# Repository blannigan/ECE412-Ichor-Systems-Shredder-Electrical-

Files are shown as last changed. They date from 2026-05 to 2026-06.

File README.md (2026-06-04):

# Universal Plastic Shredder V2.0 — Electrical System

**ECE 412 Senior Project Development I/II · Portland State University · Winter–Spring 2026**

Repository owner: **MME / Ichor Systems** ([@blannigan](https://github.com/blannigan)) — transferred from the EE team at the end of term for long-term stewardship.

Industry Sponsor: **MME / Ichor Systems** (Bridget Lannigan)  
Faculty Advisors: Prof. Andrew Greenberg, Dr. Jonathan Bird (EE), Robert Paxton (ME)

**Team "I'm so Shredded inc." — original authors, retained as collaborators with write access:**

| Name | Email |
|---|---|
| Bao Nguyen | baon@pdx.edu |
| Fearghus Tyler | fearghus@pdx.edu |
| Yaqoub Rabiah | yrabiah@pdx.edu |
| Fox Kang | foxkang@pdx.edu |

---

## Project Overview

Ichor Systems generates significant plastic waste (PVC, polypropylene, LDPE) during semiconductor equipment manufacturing. Existing commercial shredders are either too expensive or underpowered for their thick-material needs (0.25–0.5" rigid sheets). This project designs and builds the **electrical control and power system** for a new industrial-grade plastic shredder — Universal Plastic Shredder V2.0.

The mechanical structure and cutting blades are handled by a separate ME team. The EE team is responsible for:

- VFD-based motor control (3–5 HP, target 70–90 RPM output shaft speed)
- HMI operator interface (AutomationDirect EA1-T4CL C-more Micro-Graphic touch panel, serial to the PLC)
- Safety systems: two-hand start, emergency stop, lid interlock, overload/overcurrent protection
- PLC ladder logic for control sequencing (DirectLogic 205 / Direct Automation)
- Status indicator lights (Power, Running, Fault)
- Electrical protection: fuses, breakers, motor contactor, thermal shutdown

Design follows **NFPA 70 (NEC)** guidance and **NEMA enclosure** practices. Total project budget is $3,000 (EE portion ~$1,000).

---

## Requirements Summary

**Must:**
- Shred plastic into ~1-inch pieces when integrated with ME system
- Use a controllable VFD; support 3–5 HP motor at 70–90 RPM
- Follow NFPA-70 (NEC) electrical design guidance
- Include emergency stop, overcurrent/overload protection, and at least one safety interlock
- Include an HMI for operator control and status display
- Stay within the **$1,000 EE-team budget** (the overall $3,000 project budget is split across ME and EE; EE owns $1,000)

**Should:**
- Include clear status and fault indicator lights
- Follow NEMA enclosure guidelines
- Have clearly labeled controls

**May (if time/budget allow):**
- Wireless monitoring (read-only)
- Data logging
- Additional safety sensing (capacitive touch, thermal)

---

## Repository Structure

```
docs/           Numbered project documents (term1_week04_Project_Proposal → term2_week10_Final_Report)
BOM/            Bill of materials and component selection spreadsheets
CAD/            Mechanical CAD zip archive and Inventor part files (Part1–Part10)
electrical/     Circuit logic diagrams and deadman circuit documentation
PLC/            Shredder ladder logic program and point list (.xlsx / .pdf)
HMI/            HMI project file (MagicPanel .mgp)
```

---

## Final Report

The EE final report lives in `docs/term2_week10_Final_Report/`:

- **`docs/term2_week10_Final_Report/Final_Report.pdf`** — the built report (PSU MCECS style).
- **`docs/term2_week10_Final_Report/src/Final_Report.tex`** — LaTeX source.
- **[`docs/term2_week10_Final_Report/Report_Setup.md`](docs/term2_week10_Final_Report/Report_Setup.md)** — **how to build, edit, and
  regenerate the report** (toolchain, packages, compile steps, and how to
  rebuild the point-list appendix from `PLC/Point_List.xlsx`). Start here if you
  want to work on the report.
- `docs/term2_week10_Final_Report/src/appendix_pointlist.tex` / `docs/term2_week10_Final_Report/src/gen_pointlist.py` — the auto-generated
  point-list appendix and its generator.

---

## System Architecture

**Hardware subsystems:**
- AC power input → main disconnect (PowerTec 71008) → branch fuses / breakers
- 24 VDC supply (Mean Well NDR-480-24) for control wiring
- Mitsubishi SD-N35 motor contactor (E-stop hardwired in series with the coil)
- VFD (Huanyang HY02D211B-T), motor speed and direction driven by a 0–10 V analog command from the PLC and a hardwired RUN_FWD / RUN_REV / RESET trio
- 3–5 HP motor + gearbox (ME interface)
- AutomationDirect EA1-T4CL C-more Micro-Graphic HMI (operator interface)
- Safety circuit: two-hand start (deadman) buttons, E-stop, motor contactor, capacitive-touch safety input (wired to PLC X7)

**PLC (DirectLOGIC 205 rack with H2-DM1E CPU):**
The PLC is the system controller. All run-permit logic, jam recovery, the
3-strike lockout, and the HMI screen-change behavior live in the ladder
program (see Section 6 of the Final Report and `PLC/Point_List.pdf` for the
full I/O map). Modules in the rack:

| Slot | Module | Role |
|---|---|---|
| 0 | H2-DM1E | CPU + Ethernet |
| 1 | D2-08ND3 | 8-point DC discrete input (pushbuttons, E-stop monitor, VFD fault, cap touch) |
| 2 | F2-08AD-1 | 8-channel analog current input (VFD motor current monitor) |
| 3 | F2-04RTD | 4-channel RTD input (motor temperature, future) |
| 4 | D2-08TR | 8-point relay output (VFD RUN_FWD / RUN_REV / RESET, panel LEDs) |
| 5 | F2-08DA-2 | 8-channel analog voltage output (0–10 V speed reference to VFD VI) |

Program file: `PLC/src/Shredder_Ladder_Logic_v1.dmd`
Industrial standard: the entire control program and the operator interface
are built on AutomationDirect DirectLOGIC / Do-more / C-more hardware
rather than a hobby-grade microcontroller stack. ESP32 / Arduino were
considered for the HMI early on and rejected: the sponsor build needs an
industrial-rated touch panel and a PLC-based control program for
maintainability, safety review, and alignment with NFPA 79 / NEMA practice.

**HMI (EA1-T4CL C-more Micro-Graphic, `HMI/HMI_413.mgp`):**
Four screens, 27 PLC tags. The HMI is a display + button panel only; all
logic runs in the PLC ladder program. Screens:

  1. MOTOR CONTROL  — forward / reverse / stop, speed adjust (V2000)
  2. MOTOR TELEMETRY — frequency, current, voltage, RPM read-back
  3. ERROR (red backlight) — jam, capacitive trip, and E-stop indicators
  4. TEST — engineering / commissioning screen (soft deadman, soft jam)

**Operator workflow:**
1. Power on → safety check
2. Press two-hand start buttons simultaneously to run motor
3. Hand-feed plastic sheets into shredder
4. Normal stop via Stop button, or E-stop if needed
5. Collect shredded output (~1-inch pieces)

---

## Prior Work

A 2023–2024 PSU capstone team built a working 2 HP plastic shredder for the EPL that shredded household plastics with basic VFD, two-hand start, and E-stop. This project scales to industrial-grade plastics and adds motor current monitoring, automatic jam-clearing (auto forward/reverse), thermal shutdown, improved safety interlocks, a proper contactor, and a full HMI.

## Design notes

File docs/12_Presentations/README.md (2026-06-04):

# Presentations

PowerPoint decks the team built for advisor / sponsor reviews and
the final demo. Imported from Google Drive at end of term.

| # | Deck | When |
|---|---|---|
| 01 | `01_Slides_Deck_1.pptx` | First Universal Plastic Shredder V2.0 review deck (early Spring) |
| 02 | `02_Slides_Deck_2.pptx` | Second review deck (mid Spring) |
| 03 | `03_Ted_Talk_2.pptx` | Class "TED talk" presentation #2 |
| 04 | `04_Final_Demo_5min.pptx` | End-of-term 5-minute demo for the capstone showcase |

The decks were authored in PowerPoint via Drive; open in PowerPoint
or LibreOffice Impress.

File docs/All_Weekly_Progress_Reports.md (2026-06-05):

# Universal Plastic Shredder V2.0 — Weekly Progress Reports

**Course:** ECE 412/413 (Spring 2026)  
**Sponsor:** MME / Ichor Systems  
**Team:** Bao Nguyen, Fearghus Tyler, Yaqoub Rabiah, Fox Kang

---

## 🔑 Key hardware referenced

| System | Part | Role / interface |
|---|---|---|
| **VFD** | Huanyang **HY02D211B-T** | Motor drive. Speed ref on **VI** (0–10 V, `PD002=1`), current monitor on **VO** (`PD054=1`), fault relay **FA/FC** (`PD052=02`), run inputs **FOR/REV/RST** (sinking to DCM). |
| **Motor** | GE **5KE182BC205B** (bench, Winter / most of Spring) → IronHorse **MTCP2-002** (production, swapped in during Week 10) | 3-phase. Bench motor: 3 HP, 230 V, FLA ≈ 7.6 A, 1750 RPM. Production motor: 2 HP, 230 V, **5.93 A**, 1735 RPM, NEMA 145TC TEFC IP55, VFD-rated 1.0 SF. Phases **U/V/W → T1/T2/T3** via 4 mm banana sockets. |
| **PLC** | DirectLOGIC 205, **H2-DM1E** CPU | DI **X0–X7** (`D2-08ND3`), relay out **Y0–Y7** (`D2-08TR`), current-in **F2-08AD-1**, 0–10 V out **F2-08DA-2**. |
| **HMI** | C-More **EA1-T4CL** | 4" touch panel, serial link to CPU. |
| **Contactor** | Mitsubishi **SD-N35** | In the hardwired E-stop chain (coil **A1/A2**); switches the VFD feed. |
| **E-stop** | Eaton **E22B1** (NC) | Drops the contactor coil; state monitored on PLC **X4**. |
| **Braking resistor** | ATO **APCS-300R30-AD** | 300 W / 30 Ω on VFD **P+/PR**. |

## 🗂️ Report index

**Winter term**

| Date | Focus |
|---|---|
| 2025-12-17 | Kickoff coordination meeting; component research begins |
| 2026-01-03 | Compare motors / HMIs / safety sensors |
| 2026-01-09 | Sponsor + advisor goal/budget review |
| 2026-01-16 | Motor-control & safety strategy; first motor+VFD bench test |
| 2026-01-23 | Electrical design starts; BOM for initial purchases; AutoCAD setup |
| 2026-02-02 | Prototype build; safety-sensor circuit |
| 2026-02-06 | Schematic + ME coordination |
| 2026-02-13 | Advisor coordination meeting |
| 2026-02-27 | Documentation & presentation prep; BOM revision |
| 2026-03-06 | Parts arrived — fit & wire the prototype |
| 2026-03-13 | VFD/motor bring-up; HMI GUI |
| 2026-03-16 | Finalize documentation before spring break |

**Spring term**

| Wk | Date | Focus |
|---|---|---|
| 1 | 2026-04-03 | Post-break reset; points list; E-stop → contactor |
| 2 | 2026-04-10 | PLC ↔ circuit integration; cap-touch (small scale) |
| 3 | 2026-04-17 | Relay-module fix; analog modules; HMI scaling |
| 4 | 2026-04-24 | Current → voltage (0–10 V) control swap; VFD reprogram |
| 5 | 2026-05-01 | Presentation; cap-touch prototype; braking resistor sizing |
| 6 | 2026-05-08 | Midterm week (light); documentation |
| 7 | 2026-05-15 | Enclosure panel build; overcurrent-signal logic |
| 8 | 2026-05-22 | Panel wiring; ME parts hand-off |
| 9 | 2026-05-30 | Documentation push (report, manual, schematics) |
| 10 | 2026-06-06 | Final report & capstone demo |

---

# Winter Term (Dec 2025 – Mar 2026)

## Report date: 2025-12-17

### ✅ Last week  ·  _hours in parentheses_

**Team Review**
- The electrical and mechanical teams held the first coordination meeting for the shredder project.
- We discussed the overall system design, safety systems, and motor-control ideas.
- The team also set up communication tools and began researching components.

**Bao Nguyen**
- Created Discord server for team communication. (1)
- Attended coordination meeting with ME team. (1)
- Began researching HMI display options. (3)

**Fearghus Tyler**
- Discussed motor requirements with mechanical team. (2)
- Attended coordination meeting with ME team. (1)
- Researched possible motor options. (2)

**Yaqoub Rabiah**
- Started researching VFD motor-control systems. (3)
- Attended coordination meeting with ME team. (1)

**Fox Kang**
- Started researching safety sensors and safety concepts. (3)
- Attended coordination meeting with ME team. (1)

### 🎯 Next week

**Team Plan**
- Continue researching components and begin building comparison tables for motors, sensors, and control systems.

**Bao Nguyen**
- Research HMI options and telemetry display ideas. (3)

**Fearghus Tyler**
- Begin creating preliminary electrical BOM. (3)

**Yaqoub Rabiah**
- Research VFD telemetry and monitoring features. (3)

**Fox Kang**
- Continue researching safety detection methods. (3)

### 🚧 Blocked

**Bao Nguyen**
- Waiting for motor requirements from mechanical team.

**Fearghus Tyler**
- Waiting for gearbox specifications.

**Yaqoub Rabiah**
- Waiting for VFD model.

**Fox Kang**
- None.

---

## Report date: 2026-01-03

### ✅ Last week  ·  _hours in parentheses_

**Team Review**
- The team continued researching electrical components for the shredder system.
- Motors, HMIs, and safety sensors were compared.
- Early ideas for the electrical control system were discussed.

**Bao Nguyen**
- Researched HMI display options. (3)
- Reviewed possible telemetry information to display. (2)

**Fearghus Tyler**
- Began building the electrical BOM for the initial test setup — motor, VFD, contactor, PLC rack + modules, HMI, breaker, power switch, and 12/10 AWG wire. (3)

**Yaqoub Rabiah**
- Compared VFD options and specifications. (3)

**Fox Kang**
- Continued safety-sensor research. (3)

### 🎯 Next week

**Team Plan**
- Narrow down hardware options and begin planning electrical architecture.

**Bao Nguyen**
- Work on system block diagram. (3)

**Fearghus Tyler**
- Expand electrical BOM. (3)

**Yaqoub Rabiah**
- Research PLC integration with VFD. (3)

**Fox Kang**
- Continue researching safety interlocks. (3)

### 🚧 Blocked

**Bao Nguyen**
- Waiting for enclosure dimensions.

**Fearghus Tyler**
- Waiting for torque specifications.

**Yaqoub Rabiah**
- Waiting for PLC to arrive.

**Fox Kang**
- Stuck on figuring out the type of technology for the safety sensor.

---

## Report date: 2026-01-09

### ✅ Last week  ·  _hours in parentheses_

**Team Review**
- The team met with the faculty advisor and industry sponsor to review project goals.
- Budget, motor power, and safety requirements were discussed.

**Bao Nguyen**
- Attended sponsor meeting. (1)
- Researched HMI communication options. (3)

**Fearghus Tyler**
- Continued the electrical BOM — added the Huanyang HY02D211B-T VFD, contactor, push buttons, PLC rack + modules, C-More EA1-T4CL HMI, circuit breaker, power switch, and 12/10 AWG wire. (3)
- Attended sponsor meeting. (1)

**Yaqoub Rabiah**
- Researched VFD control and monitoring options. (4)

**Fox Kang**
- Continued researching safety sensors. (3)

### 🎯 Next week

**Team Plan**
- Start developing electrical system architecture.

**Bao Nguyen**
- Work on system layout diagram. (3)

**Fearghus Tyler**
- Continue updating BOM. (3)

**Yaqoub Rabiah**
- Compare VFD options. (3)

**Fox Kang**
- Research safety-sensor placement. (3)

### 🚧 Blocked

**Bao Nguyen**
- Waiting for motor specs.

**Fearghus Tyler**
- Waiting for gearbox decision.

**Yaqoub Rabiah**
- Waiting on PLC.

**Fox Kang**
- Waiting on HMI.

---

## Report date: 2026-01-16

### ✅ Last week  ·  _hours in parentheses_

**Team Review**
- The electrical team reviewed motor-control strategies and safety systems.
- Design ideas for the electrical system were discussed.

**Bao Nguyen**
- Tested small motor and VFD setup. (4)

**Fearghus Tyler**
- Worked with mechanical team on gearbox ideas. (3)

**Yaqoub Rabiah**
- Reviewed VFD specifications. (3)

**Fox Kang**
- Created accident-scenario safety flow chart. (3)

### 🎯 Next week

**Team Plan**
- Continue developing electrical control-system design.

**Bao Nguyen**
- Work on electrical control-circuit layout. (3)

**Fearghus Tyler**
- Update electrical BOM. (3)

**Yaqoub Rabiah**
- Continue VFD research. (3)

**Fox Kang**
- Continue safety-system research. (3)

### 🚧 Blocked

**Bao Nguyen**
- Waiting for gearbox decision.

**Fearghus Tyler**
- Waiting for enclosure size.

**Yaqoub Rabiah**
- Waiting on equipment to program PLC.

**Fox Kang**
- Choosing the correct parts for the safety sensors.

---

## Report date: 2026-01-23

### ✅ Last week  ·  _hours in parentheses_

**Team Review**
- The team began developing the electrical design and continued coordination with the mechanical team.

**Bao Nguyen**
- Worked on electrical system design. (3)

**Fearghus Tyler**
- Updated the electrical BOM for the first round of purchases (VFD, contactor, PLC rack/modules, HMI). (3)
- Set up the AutoCAD schematic drawings per these specs — learning the workflow: creating reusable component blocks, transferring blocks between drawings, and setting up the sheet / title-block templates.

**Yaqoub Rabiah**
- Began PLC control-logic planning. (3)

**Fox Kang**
- Continued safety-system research. (3)

### 🎯 Next week

**Team Plan**
- Start building prototype circuits and system diagrams.

**Bao Nguyen**
- Design electrical circuit diagram. (3)

**Fearghus Tyler**
- Continue component sourcing. (3)

**Yaqoub Rabiah**
- Develop PLC logic structure. (3)

**Fox Kang**
- Develop safety-system concept. (3)

### 🚧 Blocked

**Bao Nguyen**
- Waiting for motor specs.

**Fearghus Tyler**
- None.

**Yaqoub Rabiah**
- None.

**Fox Kang**
- None.

---

## Report date: 2026-02-02

### ✅ Last week  ·  _hours in parentheses_

**Team Review**
- The team worked on prototype development and safety-system concepts.

**Bao Nguyen**
- Began building electrical test rig. (4)

**Fearghus Tyler**
- Worked on the electrical schematic in AutoCAD — built out component blocks and the power-distribution sheet. (3)

**Yaqoub Rabiah**
- Developed PLC control logic. (3)

**Fox Kang**
- Requested capacitive-sensor samples. (2)

### 🎯 Next week

**Team Plan**
- Continue prototype testing and system development.

**Bao Nguyen**
- Continue test-rig development. (3)

**Fearghus Tyler**
- Improve schematic design. (3)

**Yaqoub Rabiah**
- Continue PLC programming. (3)

**Fox Kang**
- Develop safety-sensor circuit. (3)

### 🚧 Blocked

**Bao Nguyen**
- Waiting for some parts to arrive.

**Fearghus Tyler**
- None.

**Yaqoub Rabiah**
- None.

**Fox Kang**
- Waiting for sensor samples.

---

## Report date: 2026-02-06

### ✅ Last week  ·  _hours in parentheses_

**Team Review**
- Continued electrical design work and coordination with the mechanical team.

**Bao Nguyen**
- Worked on wiring prototype components. (3)

**Fearghus Tyler**
- Updated the AutoCAD schematic diagrams (block edits and layer cleanup). (3)

**Yaqoub Rabiah**
- Continued PLC logic work. (3)

**Fox Kang**
- Worked on safety-system design. (3)

### 🎯 Next week

**Team Plan**
- Continue system testing and design improvements.

**Bao Nguyen**
- Continue prototype wiring. (3)

**Fearghus Tyler**
- Review schematic design. (3)

**Yaqoub Rabiah**
- Continue PLC programming. (3)

**Fox Kang**
- Continue safety-system research. (3)

### 🚧 Blocked
- None.

---

## Report date: 2026-02-13

### ✅ Last week  ·  _hours in parentheses_

**Team Review**
- The team met with the advisor to discuss project coordination and integration with the mechanical design.

**Bao Nguyen**
- Attended advisor meeting. (1)
- Worked on electrical layout planning. (2)

**Fearghus Tyler**
- Continued the AutoCAD schematic design — refining component blocks and wiring out the control sheet. (3)
- Attended advisor meeting. (1)

**Yaqoub Rabiah**
- Worked on PLC logic improvements. (3)
- Attended advisor meeting. (1)

**Fox Kang**
- Updated safety documentation. (3)
- Attended advisor meeting. (1)

### 🎯 Next week

**Team Plan**
- Continue electrical design and documentation work.

**Bao Nguyen**
- Continue planning the panel/electrical layout — place the VFD, contactor, 24 V PSU, and branch breakers, and rough out control-wire routing for the cabinet.

**Fearghus Tyler**
- Continue the wiring schematics; finalize the power-distribution and control sheets once the updated enclosure CAD arrives from the ME team.

**Yaqoub Rabiah**
- Continue refining the PLC ladder logic — deadman permissive, start/stop, and I/O mapping against the points list.

**Fox Kang**
- Continue the safety-system documentation and evaluate capacitive-sensor options for the operator-presence interlock.

### 🚧 Blocked

**Bao Nguyen**
- Panel/electrical layout depends on the ME enclosure dimensions, still pending.

**Fearghus Tyler**
- Waiting for updated CAD from ME team.

**Yaqoub Rabiah**
- PLC I/O scaling depends on the final analog-module / VFD decision, still pending.

**Fox Kang**
- Still selecting the capacitive-sensor technology before ordering parts.

---

## Report date: 2026-02-27

### ✅ Last week  ·  _hours in parentheses_

**Team Review**
- The team focused on preparing documentation and presentation materials.

**Bao Nguyen**
- Updated electrical design diagrams. (3)

**Fearghus Tyler**
- Reviewed component selections and revised the BOM — switched the production-motor candidate to a PE145TC-2-4 (2 HP, 145TC, 1800 RPM, 3-phase TEFC) and added the NBE7 circuit breaker. (3)

**Yaqoub Rabiah**
- Reviewed PLC logic. (3)

**Fox Kang**
- Updated safety documentation. (3)

### 🎯 Next week

**Team Plan**
- Continue preparing final presentation materials.

**Bao Nguyen**
- Finalize the electrical design diagrams (system block diagram and control-circuit layout) for the presentation.

**Fearghus Tyler**
- Finalize the component-selection list / BOM (VFD, PLC, HMI, contactor, breakers, PSU) for the presentation.

**Yaqoub Rabiah**
- Finalize the PLC control-logic write-up and clean up the ladder comments for the presentation.

**Fox Kang**
- Finalize the safety documentation — E-stop chain, interlocks, and the accident-scenario flow chart — for the presentation.

### 🚧 Blocked
- None.

---

## Report date: 2026-03-06

### ✅ Last week  ·  _hours in parentheses_

**Team Review**
- The team finally got the parts they requested.

**Bao Nguyen**
- Fit parts to our prototype and wire it. (3)

**Fearghus Tyler**
- Fit parts to our prototype and wire it. (3)

**Yaqoub Rabiah**
- Started figuring out C-more to program the HMI. (3)

**Fox Kang**
- Cargo delay; exploring backup plans. (2)

### 🎯 Next week

**Team Plan**
- Try figuring out the VFD phases to have a working motor.

**Bao Nguyen**
- Continue wiring the prototype and bring up the VFD + motor combo — verify phase wiring and get the motor spinning under VFD control.

**Fearghus Tyler**
- Continue fitting and landing the newly arrived parts on the protoboard and tidy up the control wiring.

**Yaqoub Rabiah**
- Continue learning C-more and building out the HMI screens (Ready/Running/Fault, start/stop, status display).

**Fox Kang**
- Pursue a capacitive-touch backup approach while waiting on the chip — breadboard a simple touch sensor and sketch the X7 stop interface.

### 🚧 Blocked

**Bao Nguyen**
- Waiting on E-stop switch.

**Fearghus Tyler**
- Schematic finalization waiting on the ME team's enclosure dimensions.

**Yaqoub Rabiah**
- Still getting C-more set up to program the HMI.

**Fox Kang**
- Cargo delay on capacitive-touch parts.

---

## Report date: 2026-03-13

### ✅ Last week  ·  _hours in parentheses_

**Team Review**
- Started wiring up our prototype and getting the VFD to work.

**Bao Nguyen**
- Work on the VFD and motor combo. (3)

**Fearghus Tyler**
- Work on the VFD and motor combo. (3)

**Yaqoub Rabiah**
- Continued developing the HMI GUI. (3)

**Fox Kang**
- Get the capacitive-touch chip and prepare for the demo. (3)

### 🎯 Next week

**Team Plan**
- Finalize the documentation before spring break.

**Bao Nguyen**
- Continue VFD/motor bring-up — tune the basic run parameters — and document the wiring/parameter setup before spring break.

**Fearghus Tyler**
- Continue the VFD/motor wiring and update the schematics to match the as-built prototype.

**Yaqoub Rabiah**
- Continue developing the HMI GUI — refine the screen layout and link the tags to the PLC.

**Fox Kang**
- Prepare the capacitive-touch chip for the demo — wire it up and verify a basic touch trip.

### 🚧 Blocked
- None.

---

## Report date: 2026-03-16

### ✅ Last week  ·  _hours in parentheses_

**Team Review**
- The team finalized project documentation and presentation materials.

**Bao Nguyen**
- Updated diagrams and documentation. (3)

**Fearghus Tyler**
- Reviewed schematic documentation. (2)

**Yaqoub Rabiah**
- Reviewed PLC control-logic documentation. (2)

**Fox Kang**
- Reviewed safety documentation. (2)

### 🎯 Next week

**Team Plan**
- Use connectors to make it easy for the ME team to install onto the shredder.
- With the extra time we have, we can implement other kinds of safety sensors.

**Bao Nguyen**
- Add quick-connect connectors at the panel boundary so the ME team can plug in the electrical system during shredder install.

**Fearghus Tyler**
- Update the schematics and wiring diagrams to show the connectorized field/cabinet interface.

**Yaqoub Rabiah**
- Continue the PLC/HMI documentation and keep the points list in sync with the logic.

**Fox Kang**
- Use the extra time to explore additional safety sensors (e.g., lid interlock, light curtain) beyond the capacitive touch.

### 🚧 Blocked
- None.

---

> _Spring break between 2026-03-16 and 2026-04-03._

---

# Spring Term (April – June 2026)

## Week 1 — Report date: 2026-04-03

### ✅ Last week  ·  _hours in parentheses_

**Team Review**
- Refocused on getting back on track after spring break (3 hours)

**Bao Nguyen (4)**
- Redoing the points list in the sponsor's preferred style — `PLC/Point_List.xlsx` is the source of truth for every X/Y and analog point. (4)
- Installed and wired the E-stop button (Eaton **E22B1** NC mushroom) in series with the **SD-N35** contactor coil A1 (A2 → PSU −V); PLC **X4** taps the A1 node to monitor the chain. (1)

**Fearghus Tyler**
- Continued the AutoCAD wiring schematics/model to match the points list — keeping the component blocks in sync with the I/O map. (2)
- Continued support in wiring and design aspects of the protoboard. (1)
- Revised 3D model to accommodate sponsor feedback. (1)

**Yaqoub Rabiah**
- Figured out a rework of the HMI GUI. Concept wasn't liked by the sponsor. Made it sleeker in concept. (3 hours)

**Fox Kang**
- Working on capacitive-touch concept.
- Researched capacitive-sensing approaches for the operator-presence safety feature using an ESP32; scoped a touch-to-stop interlock that drops the run command via PLC input **X7**. (3 hours)

### 🎯 Next week

**Team Plan**
- Start integrating the PLC, VFD, and HMI together for our demo.
- Start materializing the final report.
- Start prototyping the capacitive-touch feature.

**Bao Nguyen**
- Start integrating PLC with the circuit to turn on and control the VFD.

**Fearghus Tyler**
- Set up the VFD to work using the analog and digital inputs instead of the default factory settings (0–10 V).
- Coordinated with the industry sponsor controls team to confirm preferred termination conventions.
- Cross-reference motor data against VFD.

**Yaqoub Rabiah**
- Start integrating PLC with the circuit to turn on and control the VFD.

**Fox Kang**
- Editing code comments and preparing connecting the module to the PLC.

### 🚧 Blocked

**Bao Nguyen**
- PLC 24 V module not suitable for contactor and LED control — need to find a relay module instead.

**Fearghus Tyler**
- Need to know where the connections will be before finishing the schematics.

**Yaqoub Rabiah**
- VFD speed-reference/RPM control wiring pending the analog-module configuration.

**Fox Kang**
- Capacitive-touch concept still pending feedback from Ichor's EE/controls team before parts selection.

---

## Week 2 — Report date: 2026-04-10

### ✅ Last week  ·  _hours in parentheses_

**Team Review**
- Made progress towards the capacitive-touch feature; works on a small scale. (5 hours)
- Integrated the PLC to the circuit. Contactor turns on with deadman switches, as well as the VFD. (8 hours)

**Bao Nguyen**
- Rewired the PLC and contactor for clean integration — moved the **SD-N35** coil out of the PLC output into the hardwired E-stop chain (previously driven by D2-08TD2 Y0). (4 hours)
- Identified the problematic module — the **F2-06AD-1** 4–20 mA current-input on the speed-reference path wasn't behaving; flagged it for a swap. (4 hours)

**Fearghus Tyler**
- Tested the protoboard with the analog and digital inputs. Ready to test with HMI. (2)
- Created some 2D wiring diagrams of different versions for field vs. internal cabinet wiring. (2)

**Yaqoub Rabiah**
- Reprogrammed the logic code for the PLC, ensuring the bits corresponded to the physical circuit. (2 hours)
- Debugged the deadman and start/stop functions to specs while integrating the PLC. (4 hours)
- Laid the foundation for the weekly progress reports. (3 hours)

**Fox Kang**
- Prototyped the ESP32 capacitive-touch sensor on a breadboard; confirmed it triggers reliably on a small test surface. (5 hours)
- Began wiring the module output toward the PLC **X7** input for the touch-to-stop interlock.

### 🎯 Next week

**Team Plan**
- Continue integrating the PLC, VFD, and HMI together for our demo.
- Start materializing the final report.

**Bao Nguyen**
- Continue integrating PLC with the circuit to turn on the VFD.

**Fearghus Tyler**
- Work with the industry sponsor to schedule a controls-team review of our materials.
- Investigated VFD behavior under current control vs. voltage control. Documented the odd current readings off the module (possibly broken?).

**Yaqoub Rabiah**
- Continue reworking the logic and HMI design for further integration.

**Fox Kang**
- Tune sensitivity and debounce on the cap-touch prototype; reduce false triggers before PLC integration.

### 🚧 Blocked

**Bao Nguyen**
- Waiting on the relay module to properly interface the PLC output with the contactor and indicator LEDs.

**Fearghus Tyler**
- Need to know their final motor specs.

**Yaqoub Rabiah**
- RPM control is acting weird.

**Fox Kang**
- Cap-touch prototype gets false triggers from electrical noise near the panel; needs filtering before PLC integration.

---

## Week 3 — Report date: 2026-04-17

### ✅ Last week  ·  _hours in parentheses_

**Team Review**
- Integrating PLC, HMI, VFD and motor. (8 hours)

**Bao Nguyen**
- Investigated why the 12–24 VDC transistor output module (**D2-08TD2**) was not behaving like a proper on/off switch. Discovered that although it functions as a switch, the lowest output voltage is still too high to reliably control devices that require a clean digital signal, such as the contactor. (4)
- Located a **D2-08TR** 8-ch relay-output module (dry contact, sinking, common to PSU −V) in the Power Lab and wired it in to properly interface the PLC output with external loads. Tested it using the on-module indicator lights to confirm correct switching. (2)
- Began studying the analog modules — **F2-08AD-1** (4–20 mA current in, Slot 3) and **F2-08DA-2** (0–10 V out, Slot 6) — to work out their wiring, scaling, and integration method. (6)

**Fearghus Tyler**
- Proposed switching from current control to voltage control (0–10 V) to the team and sponsor. (1)
- Updated 2D schematic to reflect planned analog module swap. (2)
- Revised 3D control-panel model to show new voltage-module placement and wire routing.

**Yaqoub Rabiah**
- Integrated a scale for RPM control from the HMI to the PLC. (2 hours)
- Added forward and reverse capabilities into PLC logic and integrated it into the HMI. (5 hours)
- Reworked the numerical displays on the HMI main page — a voltage / current / frequency / RPM read-out section (some fields not yet operational, pending the analog/telemetry scaling). (2 hours)
- Debugged the connection between the PLC and HMI. The protocols weren't matching. (2 hours)
- Found a problem with the current-control module and tried to debug. (4 hours)

**Fox Kang**
- Continued bench prototyping of the cap-touch module; worked on suppressing false triggers from electrical noise near the panel. (4 hours)

### 🎯 Next week

**Team Plan**
- Figure out the problem of the low amperage variance in the current-control module.

**Bao Nguyen**
- Continue studying the analog module — determine the correct field wiring and the PLC scaling so the VFD speed reference and motor-current feedback read correctly.

**Fearghus Tyler**
- Reprogrammed VFD parameters from current-control to voltage-control (0–10 V) following the analog-module swap — `PD002=1` for the **VI** 0–10 V speed reference, motor-current monitor on **VO** via `PD054=1`. (3)
- Bench-tested VFD response to 0–10 V signal from PLC; verified linear RPM control within expected range. (2)
- Updated schematics and 2D wiring diagrams to reflect final analog module configuration and E-stop logic paths. (3)
- Generated updated 3D enclosure model for ICHOR's final design package. (2)

**Yaqoub Rabiah**
- Fix logic for the cc module.

**Fox Kang**
- Prepare cap-touch module output for wiring to PLC X7 and test the touch-trip stop.

### 🚧 Blocked

**Bao Nguyen**
- Currently working on understanding how the analog module is wired and configured within the PLC system. Still determining the correct wiring for the analog inputs/outputs and how the signals should be scaled and interpreted by the PLC. Further testing and documentation review are needed before integration with the rest of the system.

**Fearghus Tyler**
- Troubleshooting current-controlled VFD motor control; running into issues with ranges.

**Yaqoub Rabiah**
- Can't seem to program the current-control module such that the range is more than 0–0.3 mA.

**Fox Kang**
- Can't wire the cap-touch module to X7 until the PLC integration is sorted out.

---

## Week 4 — Report date: 2026-04-24

### ✅ Last week  ·  _hours in parentheses_

**Team Review**
- Swapped current control with voltage control module, thus ending current-control confusion.

**Bao Nguyen**
- Swapped the current-input module for the **F2-08DA-2** 0–10 V analog-output module (drives VFD **VI**) and read the configuration docs. Found the V-memory bits holding the scaled RPM from the Do-more scaling instruction (with Yaqoub). (4)
- Working with Fearghus on reprogramming the VFD. (2)

**Fearghus Tyler**
- Tested and reprogrammed the VFD to match the move from the current-controlled to the voltage-controlled module — set `PD002=1` and verified 0 V = 0 Hz, 10 V = max frequency on **VI**. (4)
- Prepare any remaining VFD/PLC/HMI integration specs before demo.

**Yaqoub Rabiah**
- Reprogrammed the PLC to accommodate the new module. (2 hours)
- Added LED logic — **Y0** green (forward) / **Y1** yellow (reverse) — and swapped bits for easier wiring (VFD **FOR=Y6, REV=Y7, RST=Y5**, sinking to DCM). (1 hour)
- Added E-stop logic (monitored on **X4**) and a warning-light output (**Y4** → Wamco 525, 28 VDC) for safety. (1 hour)

**Fox Kang**
- Refined cap-touch firmware/code comments and prepped the module for hand-off to PLC integration. (3 hours)

### 🎯 Next week

**Team Plan**
- Do the presentation.

**Bao Nguyen**
- Support presentation prep and start sourcing the remaining parts — relay module, enclosure, and braking resistor.

**Fearghus Tyler**
- Figure out any last-minute parts we could integrate.
- Investigate braking resistor.

**Yaqoub Rabiah**
- Get ready for presentation.

**Fox Kang**
- Prepare cap-touch demo material for the presentation.

### 🚧 Blocked

**Bao Nguyen**
- None — presentation week, no blockers.

**Fearghus Tyler**
- None.

**Yaqoub Rabiah**
- None.

**Fox Kang**
- Awaiting the final cap-touch parts/relay before the full PLC hand-off.

---

## Week 5 — Report date: 2026-05-01

### ✅ Last week  ·  _hours in parentheses_

**Team Review**
- Did presentation. (2 hours)
- Prototyped capacitive touch. (2 hours)

**Bao Nguyen**
- Worked with Fox to tune and build a prototype of the CTSI capacitive-touch safety interface. (2)
- Identified new parts needed — a dynamic braking resistor (ATO **APCS-300R30-AD**, 300 W / 30 Ω on VFD **P+/PR**) and the enclosure.

**Fearghus Tyler**
- Sized the dynamic braking resistor (~30 Ω, 300 W for VFD **P+/PR**) — landed on the ATO **APCS-300R30-AD**. (1)
- Got started on a user manual. (2)
- Receiving final supplies from industry sponsors (enclosure, braking resistor, relay for integrating capacitive touch). (1)

**Yaqoub Rabiah**
- Worked on presentation slides. (1 hour)

**Fox Kang**
- Worked with Bao to tune the ESP32 CTSI capacitive-touch prototype (still on a breadboard); confirmed the touch-to-stop concept on the bench. Started planning the move to a soldered, enclosed module. (2 hours)

### 🎯 Next week

**Team Plan**
- Work on enclosure.

**Bao Nguyen**
- Continue identifying and ordering remaining parts (braking resistor, enclosure, relay) and help start the enclosure build.

**Fearghus Tyler**
- Build and test.

**Yaqoub Rabiah**
- Try integrating overcurrent signal.

**Fox Kang**
- Continue developing the CTSI capacitive-touch module toward panel integration — finalize the sensor circuit and the X7 interface.

### 🚧 Blocked

**Bao Nguyen**
- Can't progress on the enclosure build until the enclosure and remaining parts (braking resistor, relay) arrive from the sponsor.

**Fearghus Tyler**
- We can't test a lot of the functionality we had aimed for due to no shredder prototype built yet.

**Yaqoub Rabiah**
- Waiting for parts.

**Fox Kang**
- Waiting on the relay for integrating capacitive touch.

---

## Week 6 — Report date: 2026-05-08

### ✅ Last week  ·  _hours in parentheses_

**Team Review**
- Not much (midterm exam week).

**Bao Nguyen**
- Nothing — exam week.

**Fearghus Tyler**
- Midterm exams took priority; we mostly worked on documentation.
- Minor schematic changes based on the PLC logic for switching.

**Yaqoub Rabiah**
- Not much also (exam week).

**Fox Kang**
- Exam week — minimal progress; reviewed cap-touch integration plan.

### 🎯 Next week

**Team Plan**
- Work on enclosure setup.

**Bao Nguyen**
- Resume parts sourcing and enclosure prep after exams.

**Fearghus Tyler**
- Get the last parts from Ichor Systems.

**Yaqoub Rabiah**
- Try integrating overcurrent signal.

**Fox Kang**
- Resume cap-touch integration once the relay arrives.

### 🚧 Blocked

**Bao Nguyen**
- Exam week — no project time; also waiting for parts.

**Fearghus Tyler**
- Waiting for parts.

**Yaqoub Rabiah**
- Waiting for parts.

**Fox Kang**
- Waiting for parts.

---

## Week 7 — Report date: 2026-05-15

### ✅ Last week  ·  _hours in parentheses_

**Team Review**
- Set up the control panel to go inside the enclosure. (5 hours)
- Worked on the overcurrent-signal integration. (10 hours)

**Bao Nguyen**
- Helped lay out and wire the control panel into the enclosure — landed 12 AWG THHN power runs (rated 20/25/30 A at 60/75/90 °C per NEC 310.16; motor FLA ≈ 7.6 A) and ferruled 16–18 AWG control wiring; supported the overcurrent signal into **X5**. (12 hours)

**Fearghus Tyler**
- We got our enclosure, so I worked on the CAD designs for the panel design and additional panel DWGs. (4)
- Did a lot of troubleshooting and design changes for a clean enclosure. (3)
- Helped Fox periodically with the cap-touch module. (1)

**Yaqoub Rabiah**
- Wrote logic that takes the overcurrent signal and runs an unjam algorithm to clear the shredder — VFD fault relay **FA/FC** programmed `PD052=02` → +24 V into PLC **X5**; the routine pulses **Y5 → VFD RST** (~500 ms) with a 3-strike lockout. (10 hours)
- Helped design the enclosure layout. (1 hour)
- Drilled holes on the panel that holds the major components (VFD, contactor, circuit breakers, etc.). (1 hour)
- Helped wire the components in the enclosure. (2 hours)

**Fox Kang**
- Worked on the ESP32 CTSI module with Fearghus's help toward wiring it into panel **X7**; hit a bug where it works powered from a PC (USB) but bugs out standalone on the wall-outlet supply — a grounding / clean-power issue. Began soldering the module off the breadboard. (4 hours)

### 🎯 Next week

**Team Plan**
- Finish up the enclosure setup and make sure it works — plug 'n' play.

**Bao Nguyen**
- Continue enclosure wiring and verify panel integration — confirm relay-driven contactor switching and the overcurrent signal into the PLC.

**Fearghus Tyler**
- Work on the final documentation / user manual / designs.

**Yaqoub Rabiah**
- Finish enclosure setup.
- Make sure logic works.
- Set up cap touch.

**Fox Kang**
- Integrate and test the cap-touch module on X7 in the enclosure.

### 🚧 Blocked

**Bao Nguyen**
- Can't validate the overcurrent trip threshold without a real shredding load — no shredder prototype to test on yet.

**Fearghus Tyler**
- Still no prototype shredder to test on.

**Yaqoub Rabiah**
- Overcurrent-clear algorithm can't be tuned against real jam currents until a prototype exists; limited to bench simulation.

**Fox Kang**
- CTSI module works on PC USB but bugs out on the standalone wall supply (grounding/noise); needs a stable supply before it can trip **X7** reliably.

---

## Week 8 — Report date: 2026-05-22

### ✅ Last week  ·  _hours in parentheses_

**Team Review**
- Continued enclosure wiring and panel troubleshooting; coordinated parts hand-off with the mechanical team.
- Roughly 20 team-hours this week.

**Bao Nguyen**
- Continued wiring/troubleshooting the control panel and verifying PLC I/O against the points list. (14 hours)

**Fearghus Tyler**
- Worked on wiring the panel / troubleshooting. (5)
- Helped the mech team get their parts (at long last). (3)

**Yaqoub Rabiah**
- Continued debugging PLC logic against the wired panel; verified overcurrent-clear routine behavior. (6 hours)

**Fox Kang**
- Built up the CTSI module — received the 24 V→3 V converter (to run the ESP32 off the panel 24 V), an optocoupler to isolate the output into **X7**, and an enclosure box; soldering it together off the breadboard. Accidentally fed 24 V into the ESP32 while wiring and fried it; sourced and installed a replacement. (4 hours)

### 🎯 Next week

**Team Plan**
- Finish the panel/enclosure wiring and shift focus to final documentation — final report, user manual, and schematics.

**Bao Nguyen**
- Finalize the as-built wiring documentation and points list, and wrap up any remaining panel work.

**Fearghus Tyler**
- Help assemble the first edition of the shredder.

**Yaqoub Rabiah**
- Document the PLC control logic and HMI, and verify the logic on the bench setup.

**Fox Kang**
- Finalize and document the capacitive-touch module and bench-test the touch trip.

### 🚧 Blocked

**Bao Nguyen**
- Integrated/load testing still blocked — no completed shredder; work limited to bench checks and documentation.

**Fearghus Tyler**
- Waiting on the ME team to finish the shredder frame before final install and testing.

**Yaqoub Rabiah**
- Can't validate the control logic under real motor load without the mechanical prototype.

**Fox Kang**
- Replacement ESP32 in and powered via the 24 V→3 V converter; still finishing the soldered/enclosed build and verifying the optocoupler trips **X7** cleanly.

---

## Week 9 — Report date: 2026-05-30

### ✅ Last week  ·  _hours in parentheses_

**Team Review**
- Focused on documentation — drafting the final report, the user manual, and exporting the final schematics/diagrams for the report appendix.

**Bao Nguyen**
- Wrote the EE sections of the final report (wiring, sizing, safety) and finalized the as-built wiring documentation and points list. (16 hours)

**Fearghus Tyler**
- Continued the final documentation and user manual; exported the final schematics and the 3D enclosure model for the design package. (8 hours)

**Yaqoub Rabiah**
- Documented the PLC control logic and HMI screens; wrote up the control-logic section of the report. (8 hours)

**Fox Kang**
- Finished the soldered, enclosed CTSI module (ESP32 + 24 V→3 V converter + optocoupler to **X7**) and documented its design for the report. (6 hours)

### 🎯 Next week

**Team Plan**
- Finish and submit the final report, complete the user manual, and prepare the end-of-term demo/poster.

**Bao Nguyen**
- Finalize the wiring documentation (as-built diagrams, points list) and complete the EE sections of the final report.

**Fearghus Tyler**
- Finish user manual and export final schematics/DWGs for the report appendix.

**Yaqoub Rabiah**
- Finalize PLC/HMI documentation and write up the control-logic section.

**Fox Kang**
- Document the cap-touch module and write up its section.

### 🚧 Blocked

**Bao Nguyen**
- Final end-to-end/load testing still not possible — no completed shredder; report documents bench results only.

**Fearghus Tyler**
- Mechanical prototype still not built, so the install-and-test parts of the user manual are based on the bench setup.

**Yaqoub Rabiah**
- Can't capture real run/jam data for the report without a working shredder; the analog current monitor (VFD **VO** → **F2-08AD-1** CH1) is wired but still needs scaling/calibration.

**Fox Kang**
- Couldn't demonstrate the cap-touch trip on the full machine — only on the bench.

---

## Week 10 — Report date: 2026-06-06

### ✅ Last week  ·  _hours in parentheses_

**Team Review**
- Completed and submitted the final report and user manual, and presented at the capstone demo/expo.

**Bao Nguyen**
- Completed EE report sections (wiring, sizing, safety) and supported the final demo. (4 hours)
- Production motor arrived — swapped the GE 5KE182BC205B bench motor for the **IronHorse MTCP2-002** (2 HP, 230 V, 5.93 A FLA, 4-pole, 1735 RPM, NEMA 145TC TEFC IP55, VFD-rated 1.0 SF). Re-landed U/V/W on the panel-mount banana sockets and re-tagged the as-built docs (`VFD/Motor_Nameplate.md`, `ai/components.md`, `ai/io_map.md`). The VFD parameter set still carries the GE bench values; reprogramming PD141 / PD142 / PD144 (230 / 5.93 / 1735) and re-tuning the over-torque trip (`PD124 × PD142` → 8.9 A vs. the previous 11.4 A) is captured on the [Open Work punch list](../docs/term2_week11_Open_Work.md).

**Fearghus Tyler**
- Finalized the user manual and design package; delivered final schematics and 3D enclosure model. (8 hours)

**Yaqoub Rabiah**
- Finalized PLC/HMI control documentation and supported the demo. (8 hours)

**Fox Kang**
- Finalized the capacitive-touch module documentation and demonstrated the touch-to-stop safety feature. (6 hours)

### 🎯 Next week

**Team Plan**
- Term complete — project handed off to the sponsor.

**Bao Nguyen**
- N/A — end of term.

**Fearghus Tyler**
- N/A — end of term.

**Yaqoub Rabiah**
- N/A — end of term.

**Fox Kang**
- N/A — end of term.

### 🚧 Blocked

**Bao Nguyen**
- Completely blocked by the ME team --- they have no built shredder for us to test against or mount the panel on; the final report documents bench results only.

**Fearghus Tyler**
- None — end of term.

**Yaqoub Rabiah**
- Telemetry was never fully implemented: the HMI has a voltage / current / frequency / RPM read-out section, but some fields are non-operational. The analog motor-current monitor (VFD **VO** → **F2-08AD-1** CH1) is wired but only partially working — still needs scaling/calibration. Ran out of time; documented as future work.

**Fox Kang**
- None — end of term.

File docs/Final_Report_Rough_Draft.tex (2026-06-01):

\documentclass[hidelinks,12pt]{article}
\usepackage[utf8]{inputenc}

\usepackage[letterpaper, margin=1in]{geometry}
\usepackage{graphicx}
\usepackage{float}
\usepackage[labelfont=bf]{caption}
\usepackage{setspace}
\usepackage{fancyhdr}
\usepackage{enumitem}
\usepackage{hyperref}
\usepackage{xcolor}
\usepackage{titlesec}
\usepackage{tcolorbox}
\usepackage{colortbl}
\usepackage{booktabs}
\usepackage{parskip}
\usepackage{tabularx}
\usepackage{xltabular}
\usepackage{tikz}
\usepackage{pdfpages}
\usepackage{pdflscape}
\usepackage{newunicodechar}
\newunicodechar{ }{~}

\graphicspath{{images/}{./}}
\hypersetup{hidelinks}
\linespread{1.2}
\widowpenalty=8999
\clubpenalty=8999
\setlength{\headheight}{15pt}

%%%%% Portland State University official colors (MCECS report style)
\definecolor{PSUgreen}{RGB}{106,127,16}
\definecolor{PSUblue}{RGB}{0,117,154}
\definecolor{PSUgray}{RGB}{71,67,52}

% Section colors: green sections, blue subsections
\titleformat{\section}{\color{PSUgreen}\normalfont\Large\bfseries}{\color{PSUgreen}\thesection}{1em}{}
\titleformat{\subsection}{\color{PSUblue}\normalfont\large\bfseries}{\color{PSUblue}\thesubsection}{1em}{}
\titleformat{\subsubsection}{\color{PSUblue}\normalfont\normalsize\bfseries}{\color{PSUblue}\thesubsubsection}{1em}{}

% Helper for rough-draft notes and questions
\newcommand{\todo}[1]{\textcolor{red}{\textbf{[TODO: #1]}}}
\newcommand{\note}[1]{\textcolor{PSUblue}{\textit{[NOTE: #1]}}}
\newcommand{\question}[1]{\textcolor{magenta}{\textbf{[QUESTION: #1]}}}

\title{
    \vspace{-1in}
    \textbf{Universal Plastic Shredder V2.0}\\
    \large Electrical Control and Power System\\
    \normalsize \textbf{Final Report - Rough Draft}
}
\author{
    Team 07: I'm So Shredded INC\\
    Bao Nguyen, Fearghus Tyler, Yaqoub Rabiah, Fox Kang\\
    \texttt{baon@pdx.edu, fearghus@pdx.edu, yrabiah@pdx.edu, foxkang@pdx.edu}\\[4pt]
    Industry Sponsor: MME / Ichor Systems (Bridget Lannigan)\\
    Faculty Advisors: Prof. Andrew Greenberg, Dr. Jonathan Bird (EE), Robert Paxton (ME)\\[4pt]
    ECE 412 Senior Project Development I/II\\
    Portland State University, Winter--Spring 2026
}
\date{Rough Draft Submission: May 31, 2026}

\begin{document}

%----------------------------------------------------------------------------------------
%	TITLE PAGE
%----------------------------------------------------------------------------------------
\begin{titlepage}
\thispagestyle{empty}
\newcommand{\HRule}{\rule{\linewidth}{0.5mm}}
\centering

\HRule \\[0.4cm]
{\huge\color{PSUgreen}\bfseries Universal Plastic Shredder V2.0 \\[0.4cm] \Large\emph{Electrical Control \& Power System}}\\[0.4cm]
\HRule \\[1.0cm]

\textsc{\large Portland State University \\ Maseeh College of Engineering \& Computer Science \\ Department of Electrical \& Computer Engineering}\\[1.2cm]

{\large\itshape Final Report --- Rough Draft}\\[1.0cm]

\begin{minipage}{\textwidth}
\centering\large
\emph{Team 07 --- I'm So Shredded, Inc.}\\[0.3cm]
\mbox{Bao \textsc{Nguyen}} \quad \mbox{Fearghus \textsc{Tyler}} \quad \mbox{Yaqoub \textsc{Rabiah}} \quad \mbox{Fox \textsc{Kang}}\\[0.45cm]
{\normalsize \emph{Industry Sponsor:}\ \mbox{MME / Ichor Systems --- Bridget Lannigan}}\\[0.12cm]
{\small \emph{Faculty Advisors:}\ \mbox{Prof. Andrew Greenberg} \textbullet\ \mbox{Dr. Jonathan Bird (EE)} \textbullet\ \mbox{Robert Paxton (ME)}}\\[0.45cm]
{\large \today}
\end{minipage}\\[0.5cm]

\vfill
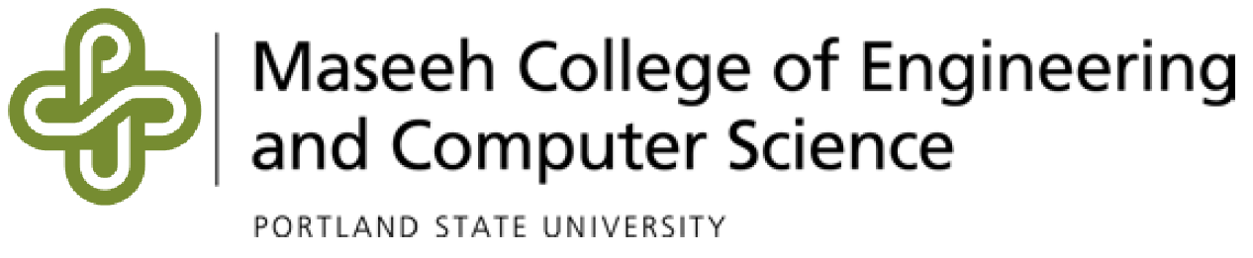
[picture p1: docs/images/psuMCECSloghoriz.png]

\vfill

\textsc{\color{PSUgray}\normalsize ECE 412/413 \\ Senior Capstone Project --- Winter--Spring 2026}\\[0.5cm]
\end{titlepage}

%----------------------------------------------------------------------------------------
%	HEADER / FOOTER
%----------------------------------------------------------------------------------------
\pagestyle{fancy}
\fancyhf{}
\fancyhead[L]{\footnotesize\textcolor{PSUgray}{Universal Plastic Shredder V2.0 --- Electrical Control \& Power System}}
\fancyhead[R]{\footnotesize\textcolor{PSUgray}{ECE 412/413}}
\renewcommand{\footrulewidth}{0.4pt}
\fancyfoot[L]{\footnotesize\color{PSUgray}\sffamily Ichor Systems Universal Plastic Shredder \textbullet\ Portland State University, MCECS}
\fancyfoot[R]{\footnotesize\color{PSUgray}\sffamily\thepage}

\noindent\rule{\textwidth}{0.4pt}

\note{This is a rough draft. Sections marked TODO, NOTE, or QUESTION indicate areas where we need to expand content, gather data, or get advisor input before the final submission. Bullet points are placeholders for fuller prose in the final version.}

\noindent\rule{\textwidth}{0.4pt}

\tableofcontents
\newpage

\section{Executive Summary}

\begin{itemize}
    \item Ichor Systems generates significant plastic waste (PVC, polypropylene, LDPE) during semiconductor equipment manufacturing, currently sent to landfill.
    \item Commercial industrial shredders cost \$10,000+ and consumer units cannot handle the thick rigid sheets (0.25--0.5 in).
    \item Our project designs the electrical control and power system for a custom industrial-grade plastic shredder, capable of shredding into 1-inch pieces.
    \item Key elements: VFD-controlled 3 HP motor at 70--90 RPM output, two-hand deadman control, hardwired E-stop, jam-detection auto-recovery with 3-strike lockout, NEMA-enclosed PLC and HMI.
    \item Total budget: \$3,000 (EE portion approximately \$1,000).
\end{itemize}

\question{Should the executive summary include high-level results / status (e.g., ``shredder validated to X HP load with Y throughput rate'') once we complete testing? Currently we have signal-chain validation but not full mechanical load testing.}

\section{Introduction}

\subsection{Background and Motivation}
\begin{itemize}
    \item Ichor Systems is a Portland-area semiconductor equipment manufacturer.
    \item Their manufacturing processes produce substantial volumes of rigid plastic sheet waste.
    \item Existing disposal route: landfill -- environmentally and economically suboptimal.
    \item A previous 2023--2024 PSU capstone team built a 2 HP household shredder for the EPL. This project scales to industrial-grade.
\end{itemize}

\subsection{Project Scope}
\begin{itemize}
    \item EE team responsibility: motor control, safety circuits, PLC logic, HMI, power distribution.
    \item ME team (separate) handles mechanical frame, blade assembly, gearbox.
    \item Integration plan: mechanical structure delivered with motor mount; EE team commissions controls.
\end{itemize}

\todo{Add a one-paragraph background on dynamic recycling / circular economy framing for the introduction.}

\section{Requirements}

\subsection{Must-Have}
\begin{itemize}
    \item Shred 0.25--0.5 in plastic sheet into approximately 1-inch pieces.
    \item Controllable VFD supporting 3--5 HP motor at 70--90 RPM output shaft speed.
    \item Follow NFPA 70 (NEC) electrical design guidance.
    \item Include emergency stop, overcurrent/overload protection, at least one safety interlock.
    \item Include an HMI for operator control and status display.
    \item Stay within \$3,000 total project budget.
\end{itemize}

\subsection{Should-Have}
\begin{itemize}
    \item Clear status and fault indicator lights.
    \item Follow NEMA enclosure guidelines.
    \item Clearly labeled controls.
\end{itemize}

\subsection{May-Have (if time/budget allow)}
\begin{itemize}
    \item Wireless monitoring (read-only).
    \item Data logging of operating hours and faults.
    \item Additional safety sensing (capacitive touch, thermal).
\end{itemize}

\section{System Architecture}

\subsection{Hardware Subsystems}
\begin{itemize}
    \item \textbf{AC power input:} 120 VAC mains $\rightarrow$ main disconnect $\rightarrow$ branch breakers $\rightarrow$ VFD and 24V PSU.
    \item \textbf{VFD:} Huanyang HY02D211B-T (2.2 kW, 110V single-phase input, 220V 3-phase output boost-type). Controlled via FOR/REV/RST digital inputs.
    \item \textbf{Motor:} bench/test unit is a GE 5KE182BC205B (3 HP, 230 V low-voltage connection, 1750 RPM, FLA 7.6 A); its nameplate drives the VFD motor parameters. \todo{Final production motor selection is TBD (3--5 HP per requirements).}
    \item \textbf{Brake resistor:} 75 $\Omega$, 500 W, connected to VFD's P/Pr terminals to handle regenerative energy during deceleration and reversal.
    \item \textbf{PLC:} AutomationDirect H2-DM1E (Do-more CPU) on DL205 base, D2-08ND3 discrete input module.
    \item \textbf{HMI:} AutomationDirect C-more Micro-Graphic EA1-T4CL 4-inch color touch panel, connected to the H2-DM1E CPU serial communication port (operator commands to the PLC; status/data back to the panel). Powered from the shared Mean Well NDR-480-24 24\,VDC supply.
    \item \textbf{Safety circuit:} Hardwired E-stop loop and two-hand deadman start; motor contactor energized through the safety chain. Access guarding at the feed is handled by the ME team's mechanical design, so no separate electrical lid interlock is used.
    \item \textbf{24V DC supply:} Mean Well NDR-480-24 (480 W) for control voltage.
\end{itemize}

\subsection{Signal Flow}
\begin{itemize}
    \item Operator inputs (deadman buttons, E-stop, reset) $\rightarrow$ PLC discrete inputs (D2-08ND3, sourcing mode).
    \item PLC outputs (D2-08TR relay module, common to PSU --V) $\rightarrow$ VFD FOR (Y7), REV (Y6), RST (Y5) inputs in sinking (NPN) mode.
    \item VFD fault relay (FC + FA, NO active-high) $\rightarrow$ PLC X5 input. X5 = HIGH when VFD trips on fault, LOW when healthy.
    \item HMI $\leftrightarrow$ PLC via serial (H2-DM1E CPU serial COM port; matched baud, parity, and stop bits on both ends).
\end{itemize}

\begin{figure}[H]
\centering
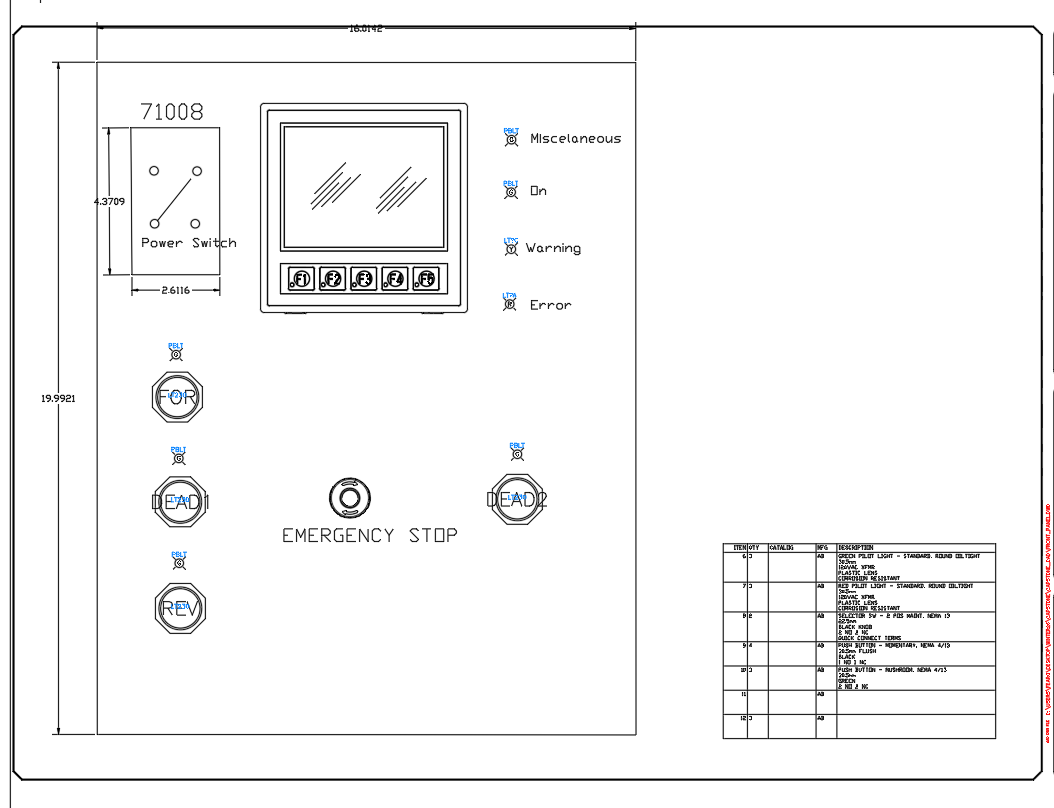
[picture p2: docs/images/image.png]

\caption{Operator control panel layout: HMI, power switch, forward/reverse and deadman pushbuttons, emergency stop, and status indicators.}
\label{fig:panel}
\end{figure}
\todo{Add a system block diagram (power + signal flow) to complement the panel layout above.}

\section{Hardware Design}

\subsection{Power Distribution}
\begin{itemize}
    \item Main disconnect / power switch: PowerTec 71008 two-pole (DPST) START/STOP switch, 120--230 VAC single-phase, rated 20 A / 3 HP max; switches both the line and neutral conductors.
    \item VFD branch breaker: 30 A C-curve DIN-rail (handles inrush, sized per NEC 430.52).
    \item 24V PSU branch breaker: 10 A C-curve DIN-rail.
    \item \textbf{Conductors:} power runs use 12 AWG copper (THHN/MTW), rated 20 A / 25 A / 30 A at the 60/75/90\,\textdegree C ampacity columns of NEC Table 310.16 -- well above the motor's 7.6 A FLA and the VFD input current. Control wiring uses 16--18 AWG, landed directly as straight stripped conductors at the terminal blocks (no ferrules used in this build).
    \item \textbf{Fuse / OCPD sizing:} branch and component fuses are sized at \textbf{125\% of the protected component's rated continuous load} per NEC 210.20(A) / 215.3. (The motor branch breaker is the exception -- NEC 430.52 permits a higher multiple of FLC to ride through inrush; running overload is handled by the VFD's electronic motor-overload function.)
    \item All branches fused individually at terminal blocks for downstream loads.
\end{itemize}

\subsection{Motor and VFD}
\label{sec:motorvfd}
The Huanyang HY02D211B-T was selected over alternatives via a decision matrix (price,
documentation, reliability). A brake resistor on the P/Pr terminals absorbs the
regenerative energy from rapid reversal during the jam-clear cycle. The drive is
programmed as shown in Table~\ref{tab:vfdparams}.

\renewcommand{\arraystretch}{1.3}
\begin{xltabular}{\textwidth}{|l|p{3.0cm}|l|X|}
\caption{Programmed VFD parameters (Huanyang HY02D211B-T).}\label{tab:vfdparams}\\
\hline
\textbf{Param} & \textbf{What it does} & \textbf{Value} & \textbf{Why this value} \\
\hline
\endfirsthead
\hline
\textbf{Param} & \textbf{What it does} & \textbf{Value} & \textbf{Why this value} \\
\hline
\endhead
\hline
\multicolumn{4}{r@{}}{\small\itshape continued on next page\,\dots}\\ \hline
\endfoot
\hline
\endlastfoot
\texttt{PD141} & Motor rated voltage & 230 V & Matches the GE test-motor nameplate (230 V low-voltage connection); sets the base of the V/Hz curve. \\ \hline
\texttt{PD142} & Motor rated current (FLA) & 7.6 A & Nameplate full-load amps; sets the drive's current limit and electronic-overload reference. \\ \hline
\texttt{PD143} & Number of motor poles & 4 & Nameplate; 4-pole $=$ 1800 RPM synchronous, so the drive resolves speed and slip correctly. \\ \hline
\texttt{PD144} & Motor rated speed & 1750 RPM & Nameplate full-load speed; with the pole count it lets the drive estimate slip. \\ \hline
\texttt{PD002} & Run / frequency source & 1 (external) & Speed comes from the external 0--10 V analog input (VI) driven by the PLC, not the keypad. \\ \hline
\texttt{PD052} & Relay output (FA/FC) function & 02 (fault) & Closes the FA--FC relay on any fault so the PLC reads a jam/trip on input X5. \\ \hline
\texttt{PD054} & Analog output (VO) function & 1 (current) & Outputs 0--10 V proportional to motor current to the PLC analog input for monitoring. \\ \hline
\texttt{PD123} & Over-torque action & 3 (trip) & Over-torque self-trips the drive (which fires the fault relay); see the note below. \\ \hline
\texttt{PD124} & Over-torque threshold & 150\% & Set between no-load current ($\sim$0.5 A) and measured jam current ($>$11 A) so normal shredding does not trip but a jam does. \\ \hline
\texttt{PD125} & Over-torque detection time & 3.0 s & The over-torque must persist 3 s before tripping, so brief load spikes (feeding a piece) do not nuisance-trip. \\ \hline
\end{xltabular}
\renewcommand{\arraystretch}{1.0}

\note{The over-torque relay function (\texttt{PD052 = 12}) did not fire the relay in our specific Huanyang revision when \texttt{PD123 = 2} (continue running). Documented as a firmware-specific limitation (see Table~\ref{tab:vfdparams}). Working configuration uses \texttt{PD052 = 02} (fault indication) and \texttt{PD123 = 3} (over-torque triggers self-trip, which fires the fault relay). The PLC then runs the unjam routine including a RST pulse to clear the VFD's latched fault state between retry attempts.}

\subsection{Safety Circuit}
\begin{itemize}
    \item E-stop: NC contact (E22B1) hardwired in series with the SD-N35 contactor coil. Pressing it drops the coil and opens the contactor, removing motor power independently of the PLC.
    \item Two-hand deadman: both buttons must be held continuously to enable the motor (evaluated by the PLC; see the Safety Functions assessment below).
    \item Access guarding: handled by the ME team's mechanical design (feed geometry), so no separate electrical lid interlock is used (this was a may-have, not a requirement).
    \item Motor contactor: the SD-N35 is energized through the hardwired safety chain, and the VFD is powered through it, so the safety chain has hardware precedence over the PLC.
\end{itemize}

\todo{Add safety circuit schematic. Reference NFPA 79 section 9 for safety-related stop functions.}

\subsection{Jam Detection Signal Chain}
\begin{itemize}
    \item VFD's multi-function relay (terminals FA, FB, FC) programmed for Fault Indication (\texttt{PD052 = 02}). \textbf{Only FA and FC are used} for jam detection; the FB (normally-closed) contact is left unconnected.
    \item Wired as an NO active-high pair: +24V (through a 500 mA fast-blow fuse) feeds the FA contact; the FC common returns to PLC X5 input on D2-08ND3 (Slot 2). When the VFD trips, FA--FC closes and +24V reaches X5.
    \item PLC sees X5 = LOW during normal operation, X5 = HIGH when VFD trips on any fault (over-torque, overvoltage, overheat, etc.).
    \item PLC ladder reads \texttt{[ X5 ]} on rising edge to detect new fault events.
    \item Wire-break failure mode is handled at the safety-circuit level by the independent hardwired E-stop loop and motor contactor, rather than at the jam-signal level.
    \item Full terminal-by-terminal wiring is given in the I/O point list (Appendix B) and the VFD parameter/wiring table (Appendix D).
\end{itemize}

\section{Software Design}

\subsection{PLC Ladder Logic Architecture}
\begin{itemize}
    \item Do-more Designer stage program (similar to grafcet / SFC).
    \item States: IDLE, RUNNING, JAM\_DETECTED, RST\_PULSE, REVERSE, RESUME, LOCKOUT.
    \item Transitions driven by deadman input, X5 jam signal, jam counter, and reset button.
\end{itemize}

\subsection{State Machine}
\begin{itemize}
    \item \textbf{IDLE} $\rightarrow$ RUNNING when both deadman buttons held AND not locked out AND startup mask done.
    \item \textbf{RUNNING} $\rightarrow$ JAM\_DETECTED on rising edge of X5 (VFD trip → fault relay fires → X5 goes HIGH).
    \item \textbf{JAM\_DETECTED} $\rightarrow$ RST\_PULSE if jam count $< 3$, $\rightarrow$ LOCKOUT if jam count $\geq 3$.
    \item \textbf{RST\_PULSE} (500 ms) $\rightarrow$ REVERSE (2 s).
    \item \textbf{REVERSE} $\rightarrow$ RESUME (brief delay) $\rightarrow$ back to RUNNING.
    \item \textbf{LOCKOUT} $\rightarrow$ IDLE only via dedicated reset button.
\end{itemize}

\subsection{Jam Counter Reset Logic}
\begin{itemize}
    \item Counter increments on each X5 rising edge (each new VFD fault triggers a jam event).
    \item Resets to 0 if motor runs cleanly for 30 continuous seconds in the RUNNING state.
    \item Also resets if deadman is released for 30 continuous seconds (session reset).
    \item Whichever condition fires first wins.
\end{itemize}

\subsection{Startup Mask}
\begin{itemize}
    \item For first 5 seconds after PLC power-up, X5 is ignored.
    \item In NO active-high wiring, this guards against transient X5 pulses during VFD initialization. Less critical than under NC wiring but kept as a defensive measure.
\end{itemize}

\subsection{HMI Programming}
\begin{itemize}
    \item Status displays: Ready, Running, Jam in progress, Lockout, Fault.
    \item Operator inputs: Speed setpoint (currently fixed in PLC), Reset button.
    \item Data displayed: Motor current (from the VFD VO analog output into PLC input F2-08AD-1 CH1 -- wired but not yet correctly scaled, see Open Issues), Jam count this session, Total runtime.
\end{itemize}

\question{We have not finalized the HMI screen layout. Should we include mock-ups in the rough draft, or wait for the final?}

\section{Safety Design}

\subsection{NFPA 79 Compliance}
\begin{itemize}
    \item Wire color coding follows NFPA 79 §13.2: Black for AC line/load, Red for AC control, Blue for DC control, Blue/W stripe for DC return, Green/Yellow for ground.
    \item This color convention is applied to every conductor in the panel.
    \item All control wires labeled at both ends.
    \item Control wires land as straight stripped conductors at the terminal blocks (no ferrules used in this build).
\end{itemize}

\subsection{Safety Functions}
\begin{itemize}
    \item \textbf{E-stop:} Category 0 stop (immediate removal of power). Hardwired --- an E22B1 NC contact in series with the SD-N35 contactor coil; pressing it drops the coil and opens the contactor independently of the PLC. Single channel; the PLC additionally monitors the state on X4 (not a safety-rated channel).
    \item \textbf{Two-hand / deadman control:} both blue pushbuttons must be held continuously to enable the motor. As-built, the two NO inputs are AND-ed in the standard PLC's ladder logic to gate the VFD run output. It is the run-permissive and the safety interlock satisfying requirement M6, but it is \emph{not} a safety-rated two-hand device per ISO 13851 Type III (no simultaneity timer, complementary contacts, or self-monitoring).
    \item \textbf{Access guarding:} handled by the ME team's mechanical design (feed geometry), so no electrical lid interlock is implemented (a lid interlock was a may-have, not a requirement).
    \item \textbf{Capacitive-touch module (planned):} a capacitive-touch safety module is on hand and the ladder logic to act on it (input X7 $\rightarrow$ stop motor + fault indication) is written, but it is \emph{not yet wired}. This is a may-have (additional safety sensing) and is not relied upon in the current build.
    \item \textbf{Overload:} the VFD's electronic motor-overload function plus the over-torque trip (see Jam Detection); equipment protection rather than a personnel-safety function.
\end{itemize}

\subsection{Performance Level (ISO 13849-1) --- Preliminary Assessment}
This is a preliminary, self-assessed determination from the as-built architecture. A formal verification needs a documented ISO 12100 risk assessment (to set the required performance level, PLr) and component reliability data (MTTFd / B10d, diagnostic coverage). Table~\ref{tab:pl} summarizes the achieved categories.

\begin{table}[H]
\centering
\renewcommand{\arraystretch}{1.3}
\caption{Preliminary ISO 13849-1 assessment of the as-built safety functions.}
\label{tab:pl}
\begin{tabularx}{\textwidth}{|p{2.5cm}|X|p{2.3cm}|}
\hline
\rowcolor{PSUgreen!12}\textbf{Safety function} & \textbf{As-built architecture} & \textbf{Category (prelim.)} \\
\hline
Emergency stop & Hardwired E22B1 NC contact in series with the SD-N35 contactor coil; opening it removes motor power. Single channel, well-tried components; PLC monitors X4 (not safety-rated). & Cat 1 (PL b--c) \\ \hline
Two-hand / deadman & Two NO buttons AND-ed in the standard PLC to gate the VFD run output. Single channel; no simultaneity check, complementary contacts, or self-monitoring. & Cat B (PL b); not ISO 13851 Type III \\ \hline
Over-torque / jam stop & VFD over-torque trip plus electronic motor overload. Equipment protection, not a personnel-safety function. & Not rated (process protection) \\
\hline
\end{tabularx}
\end{table}

Overall the control system is approximately \textbf{Category B--1 (PL b--c)}, limited by: single-channel architecture throughout; a standard (non-safety) PLC evaluating the two-hand permissive; a single contactor with no force-guided (mechanically linked) contacts and no feedback (EDM) monitoring to detect a welded contactor; and the as-built neutral-switching deviation (see the NEC note). The hardwired E-stop, built from well-tried components, is the strongest function (Category 1).

To raise the achieved PL --- for example to Category 3 / PL d, should the risk assessment require it for the rotating-blade hazard --- would need a dual-channel architecture, a safety relay or safety-rated PLC, two contactors (or force-guided contacts) with feedback monitoring, switching of the hot leg, and a synchronous two-hand module meeting ISO 13851.

\todo{Confirm with the advisor whether formal PL/SIL verification is in capstone scope. If so, document the target PLr from the ISO 12100 risk assessment and the component MTTFd / B10d and DC values to complete the calculation.}

\subsection{Failure Mode Analysis}
\begin{itemize}
    \item Wire break in jam signal: PLC sees X5 stuck LOW. Jam signal cannot fire, but the hardwired E-stop loop and motor contactor provide independent safety. Operator can also see motor stop and trigger investigation via fault-light absence.
    \item VFD loses power: the FA--FC fault relay de-energizes and opens, so X5 reads LOW (indistinguishable from healthy). The motor stops because the VFD itself is unpowered, so the condition is caught by the motor not running rather than by the jam signal.
    \item PLC fails: motor contactor drops out (safety chain bypasses PLC). Motor coasts to stop.
    \item Brake resistor disconnected: VFD will trip on overvoltage during deceleration. Motor coasts to stop. Diagnosable from VFD display.
\end{itemize}
% ============================================================================
% USER MANUAL SECTION
% ============================================================================

\newpage
\section{User Manual}

\subsection{Purpose of This Manual}
This manual provides operators, maintenance personnel, and safety officers with the procedures necessary to safely operate, monitor, and perform basic troubleshooting on the Universal Plastic Shredder V2.0 electrical control system. It assumes the user has read the full engineering report and understands the basic hazards described in Section 7 (Safety Design).

\subsection{Intended Audience and Required Training}
\begin{itemize}
    \item \textbf{Operators:} Must complete a site-specific safety briefing covering two-hand deadman operation, E-stop use, and jam recovery. No electrical troubleshooting is permitted without additional training.
    \item \textbf{Maintenance personnel:} Must be familiar with NFPA 70E arc-flash boundaries, lockout/tagout (LOTO) per 29 CFR 1910.147, and the contents of Appendix B (I/O point list) and Appendix D (VFD parameters).
    \item \textbf{Supervisors / safety officers:} Shall maintain a copy of this manual and the full engineering report adjacent to the machine or in a controlled electronic repository.
\end{itemize}

\subsection{Normal Operating Procedure}

\subsubsection{Pre-Start Checks}
\begin{enumerate}
    \item Verify the main disconnect (PowerTec 71008) is in the OFF position.
    \item Inspect the feed area for obstructions, loose plastic, or foreign objects.
    \item Verify the E-stop button is pulled out (released).
    \item Ensure both deadman pushbuttons are not pressed.
    \item Close and latch any mechanical access guards (ME team's responsibility).
\end{enumerate}

\subsubsection{Startup}
\begin{enumerate}
    \item Turn the main disconnect to ON. The HMI shall display \textbf{IDLE / READY}. The green status indicator shall illuminate.
    \item If the HMI shows a fault or lockout message, press the HMI \textbf{RESET} button (see Section \ref{subsec:faultrecovery}).
    \item To start shredding: 
        \begin{itemize}
            \item Press and \textbf{hold both blue deadman pushbuttons simultaneously}.
            \item The motor will accelerate to the programmed speed (70–90 RPM at the shaft).
            \item The red ``RUNNING'' status indicator shall illuminate.
            \item If either deadman button is released, the motor stops immediately.
        \end{itemize}
    \item Feed plastic sheet material at a moderate, steady rate. Avoid overstuffing.
\end{enumerate}

\subsubsection{Normal Shutdown}
\begin{enumerate}
    \item Release both deadman buttons. The motor will coast to a stop.
    \item Wait for the blades to come to a complete stop (minimum 5 seconds).
    \item Turn the main disconnect to OFF.
\end{enumerate}

\subsection{Emergency Stop and Safety Functions}
\begin{itemize}
    \item \textbf{To stop in an emergency:} Press the red mushroom E-stop button. Motor power is removed immediately (Category 0 stop). The HMI will show \textbf{ESTOP ACTIVE}.
    \item \textbf{To reset after E-stop:} Twist the E-stop button clockwise to release it, then press the HMI RESET button.
    \item \textbf{Two-hand deadman:} The motor runs only while both blue buttons are held. This is a permissive — not a safety-rated two-hand control per ISO 13851 Type III. Never bypass or defeat this function.
\end{itemize}

\subsection{Jam Detection and Automatic Recovery}
The control system includes an auto-reverse jam recovery feature. When an over-torque jam is detected (motor current exceeds 150\% of rated for 3 seconds):

\begin{enumerate}
    \item The VFD trips and the motor stops.
    \item The HMI displays \textbf{JAM DETECTED} and increments the jam counter.
    \item The PLC automatically:
        \begin{enumerate}
            \item Sends a 500 ms reset pulse to clear the VFD fault.
            \item Runs the motor in reverse for 2 seconds to clear the jam.
            \item Pauses briefly, then restarts forward operation.
        \end{enumerate}
    \item If the jam clears, normal operation resumes.
    \item If a jam occurs again within the same operating session:
        \begin{itemize}
            \item Jam counter increments.
            \item After the \textbf{third jam} within a session, the system enters \textbf{LOCKOUT} mode.
            \item The HMI shows \textbf{LOCKOUT — MANUAL RESET REQUIRED}.
            \item Motor cannot restart until a supervisor presses the HMI RESET button and clears the feed area.
        \end{itemize}
\end{enumerate}

\subsection{Fault Recovery and Lockout Reset}
\label{subsec:faultrecovery}
\begin{table}[H]
\centering
\caption{Fault codes and recovery actions}
\label{tab:faultcodes}
\begin{tabularx}{0.9\textwidth}{|l|X|}
\hline
\rowcolor{PSUgreen!12}\textbf{HMI Display} & \textbf{Operator Action} \\
\hline
ESTOP ACTIVE & Release E-stop button, then press HMI RESET. \\
\hline
VFD FAULT & Check VFD display for code (overvoltage, overtemp, etc.). Power cycle main disconnect. If repeated, call maintenance. \\
\hline
JAM (1 or 2) & No action — automatic recovery runs. Monitor HMI. \\
\hline
LOCKOUT (3 jams) & Clear plastic from blades manually (after LOTO), then press HMI RESET. \\
\hline
IDLE / READY & Normal. \\
\hline
\end{tabularx}
\end{table}

\subsection{Schematic and Wiring Diagrams}
The following figures show the core electrical circuits of the shredder control system. All wire colors follow NFPA 79 §13.2 (see Section 7.1). Full terminal-level details are in Appendix B (I/O point list).

\begin{figure}[H]
\centering
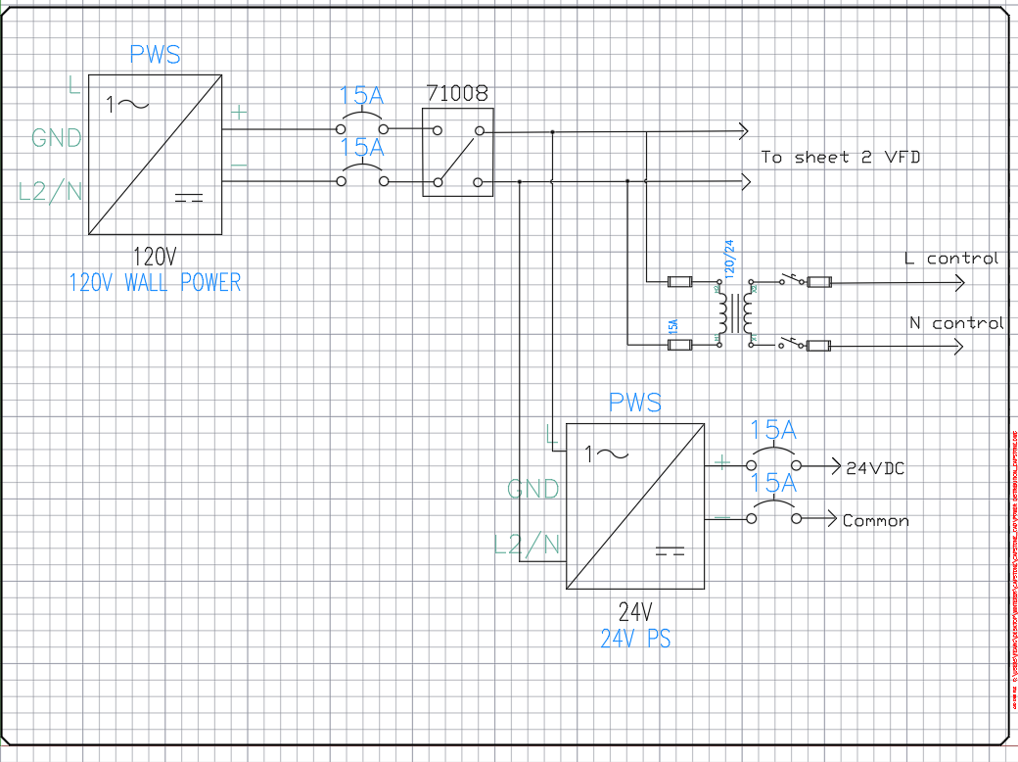
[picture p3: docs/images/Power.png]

\caption{Power distribution circuit: main disconnect, branch breakers, 24 V power supply, and VFD input.}
\label{fig:powercircuit}
\end{figure}

\begin{figure}[H]
\centering
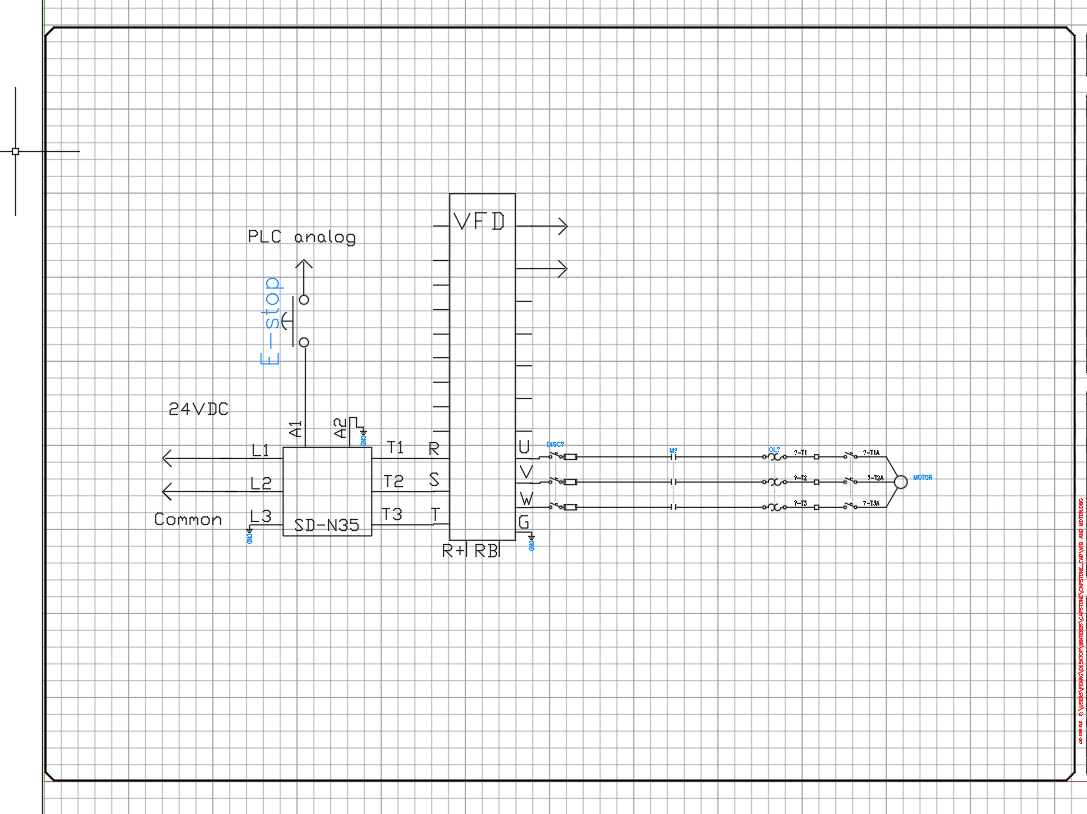
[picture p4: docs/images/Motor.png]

\caption{Motor control circuit: VFD connections to motor, brake resistor (P/Pr), and fault relay output (FA/FC).}
\label{fig:motorcircuit}
\end{figure}

\begin{figure}[H]
\centering
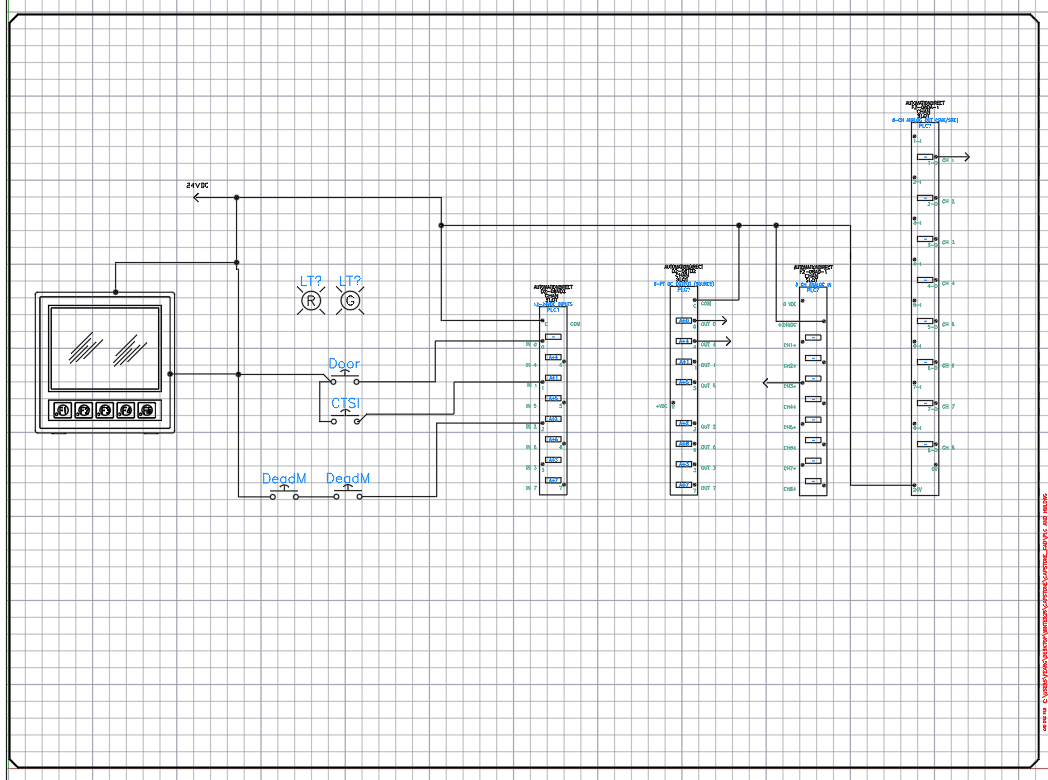
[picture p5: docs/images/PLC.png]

\caption{PLC I/O circuit: deadman buttons, E-stop monitor, VFD fault input, and VFD run/rev/reset outputs.}
\label{fig:plccircuit}
\end{figure}

\subsection{Daily and Periodic Maintenance}

\subsubsection{Operator Daily Checks}
\begin{itemize}
    \item Before first use: Verify E-stop button stops the motor immediately.
    \item Check that both deadman buttons are responsive (motor runs only when both held).
    \item Listen for unusual noises (grinding, excessive vibration).
    \item Ensure the HMI jam counter resets to zero after a clean 30-second run.
\end{itemize}

\subsubsection{Monthly Maintenance (Qualified Personnel Only)}
\begin{itemize}
    \item Perform LOTO (lockout/tagout) on the main disconnect.
    \item Open the electrical enclosure.
    \item Visually inspect for loose wires, discoloration, or burned terminals.
    \item Check that the brake resistor (75 ohm, 500w) shows no cracking or overheating signs.
    \item Verify fan operation on the VFD and power supply.
    \item Clean dust from the enclosure using low-pressure compressed air.
    \item Close and secure enclosure before re-energizing.
\end{itemize}

\subsection{Troubleshooting Guide}
\begin{table}[H]
\centering
\caption{Common issues and corrective actions}
\label{tab:troubleshooting}
\begin{tabularx}{\textwidth}{|p{2.8cm}|p{2.5cm}|X|}
\hline
\rowcolor{PSUgreen!12}\textbf{Symptom} & \textbf{Possible cause} & \textbf{Action} \\
\hline
Motor does not start & E-stop pressed & Release E-stop, reset HMI. \\
\cline{2-3}
& Only one deadman pressed & Press both simultaneously. \\
\cline{2-3}
& LOCKOUT active & Clear jam, press HMI RESET. \\
\hline
Motor runs briefly then stops & Jam detected & Let auto-reverse run. If repeated, clear plastic manually. \\
\hline
HMI blank & No 24 V power & Check Mean Well PSU input breaker (10 A) and output fuses. \\
\hline
VFD shows fault code & Overvoltage / overtemp / etc. & See VFD manual Appendix D. Power cycle. \\
\hline
Jam counter increments without jam & Over-torque threshold too low & Check PD124. Nominal = 150\%. \\
\hline
\end{tabularx}
\end{table}

\subsection{Safety Warnings Summary}
\begin{tcolorbox}[colback=red!5!white, colframe=red!70!black, title=\textbf{⚠ CRITICAL SAFETY WARNINGS}]
\begin{itemize}
    \item Never reach into the feed area while blades are moving. Wait for complete stop.
    \item Do not bypass, tape down, or modify the deadman buttons or E-stop.
    \item Lockout/tagout the main disconnect before any enclosure opening or blade service.
    \item This machine has no electrical feed interlock — the mechanical feed geometry is the primary access safeguard.
    \item If the automatic jam recovery cycles three times, \textbf{stop and manually clear} the jam.
\end{itemize}
\end{tcolorbox}

\subsection{Contact for Service and Support}
For maintenance beyond this manual, contact the Ichor Systems facilities team or the original design team (via Portland State University, ECE Department). Have the following ready:
\begin{itemize}
    \item Shredder serial number (TBD — assign upon final assembly)
    \item VFD fault code (if any)
    \item HMI jam count and lockout status
    \item Photos of any visible damage
\end{itemize}

\subsection{Revision History of This Manual}
\begin{table}[H]
\centering
\begin{tabularx}{0.7\textwidth}{|l|l|X|}
\hline
\rowcolor{PSUgreen!12}\textbf{Version} & \textbf{Date} & \textbf{Changes} \\
\hline
1.0 & 2026-05-31 & Initial release (rough draft). \\
\hline
\end{tabularx}
\end{table}

% End of User Manual Section
\section{Standards and Regulatory Compliance}

This section consolidates every electrical and machine-safety standard the design
is built against and states, for each, how it is applied to the shredder. Many of
these are referenced in passing elsewhere in this report; they are gathered here so
a reviewer (or a future maintenance team) can audit compliance in one place.

\subsection{Standards Summary Matrix}

\renewcommand{\arraystretch}{1.35}
\begin{xltabular}{\textwidth}{|p{2.4cm}|p{3.0cm}|X|}
\hline
\rowcolor{PSUgreen!12}\textbf{Standard} & \textbf{Scope} & \textbf{How it is applied here} \\
\hline
\endfirsthead
\hline
\rowcolor{PSUgreen!12}\textbf{Standard} & \textbf{Scope} & \textbf{How it is applied here} \\
\hline
\endhead
\hline
\multicolumn{3}{r}{\small\itshape continued on next page\,\dots}\\ \hline
\endfoot
\hline
\endlastfoot
NFPA 70 (NEC) & National Electrical Code -- premises wiring, motor circuits & Branch-circuit, conductor, grounding, and disconnect design (see \S\ref{subsec:nec}). \\ \hline
NFPA 79 & Electrical standard for industrial machinery & Wire color coding, supply disconnect, protective bonding, stop functions, operator devices (see \S\ref{subsec:nfpa79}). \\ \hline
NEMA 250 & Enclosure type ratings & Control enclosure selected to a NEMA type matched to the lab/shop environment (see \S\ref{subsec:nema}). \\ \hline
NEMA ICS 1/2 & Industrial control \& systems & Contactor / control device selection and marking. \\ \hline
NEMA MG 1 & Motors and generators & Motor nameplate interpretation and VFD parameterization. \\ \hline
UL 508A & Industrial control panels & Panel construction practice and short-circuit current rating (SCCR) awareness. \\ \hline
IEC 60204-1 & Safety of machinery -- electrical equipment & International counterpart to NFPA 79; used to cross-check stop categories. \\ \hline
ISO 12100 & Risk assessment / risk reduction & Framework behind the hazard analysis driving the safety circuit. \\ \hline
ISO 13849-1 & Safety-related parts of control systems (PL) & Preliminary self-assessment (Cat B--1) of the E-stop and two-hand control chain. \\ \hline
ISO 13850 & Emergency stop function & E-stop actuator type, color, and Category 0 behavior. \\ \hline
ISO 13851 & Two-hand control devices & Deadman two-hand start timing and configuration. \\ \hline
OSHA 29 CFR 1910.147 & Lockout/Tagout (LOTO) & Lockable main disconnect for energy isolation during service. \\ \hline
\end{xltabular}
\renewcommand{\arraystretch}{1.0}

\subsection{NFPA 70 -- National Electrical Code}
\label{subsec:nec}
\renewcommand{\arraystretch}{1.3}
\noindent\begin{tabularx}{\textwidth}{|p{2.5cm}|p{3.0cm}|X|}
\hline
\rowcolor{PSUgreen!12}\textbf{NEC article} & \textbf{Requirement} & \textbf{How it is applied here} \\
\hline
Art. 430.6 & Motor FLC basis & From the GE test-motor nameplate (FLA 7.6 A at 230 V); basis for all downstream sizing. Re-verified when the production motor is selected. \\ \hline
Art. 430.22 & Branch conductor sizing & Conductors sized at $\geq 125\%$ of motor FLC. \\ \hline
Art. 430.32 & Running overload & VFD electronic motor-overload (\texttt{PD142 = 7.6 A}) plus the over-torque trip. \\ \hline
Art. 430.52 & Branch short-circuit / ground-fault & 30 A C-curve breaker on the VFD branch; clears inrush without nuisance trips (inverse-time-breaker allowance). \\ \hline
Art. 430.102/.109 & Disconnecting means & Provided ahead of the controller and VFD. \\ \hline
Art. 430 Part X (430.122) & Adjustable-speed drive systems & Conductor and protection rules applied to the VFD-fed motor circuit. \\ \hline
Art. 250 & Grounding \& bonding & EGC (green / green-yellow) bonds the VFD, PSU, motor frame, and panel to a common ground bus and building earth. \\ \hline
Art. 310 & Conductor ampacity & Conductors chosen from the ampacity tables for the installed temperature rating. \\ \hline
Art. 409 & Industrial control panels & Panel layout, marking, and overcurrent considerations. \\ \hline
Art. 110.26 & Working space & Clearances around live parts maintained for safe service. \todo{Confirm final panel mounting leaves required clearance.} \\
\hline
\end{tabularx}
\renewcommand{\arraystretch}{1.0}

\note{As-built deviation flagged during the Point List review: the SD-N35 safety
contactor switches the VFD \emph{neutral} (T) leg rather than the \emph{hot} (R) leg.
NEC / NFPA 79 practice is to switch the ungrounded (hot) conductor so that opening the
contactor de-energizes the load to ground potential. Switching the grounded conductor
leaves the load at line potential when the contactor is open. This is documented in
the as-built I/O point list (Appendix B, VFD terminals) and must be corrected, or
explicitly justified and risk-assessed, before final sign-off.}

\subsection{NFPA 79 -- Electrical Standard for Industrial Machinery}
\label{subsec:nfpa79}
\renewcommand{\arraystretch}{1.3}
\noindent\begin{tabularx}{\textwidth}{|p{2.5cm}|p{3.0cm}|X|}
\hline
\rowcolor{PSUgreen!12}\textbf{NFPA 79 clause} & \textbf{Requirement} & \textbf{How it is applied here} \\
\hline
\S5.3 & Supply disconnecting means & Lockable main disconnect (PowerTec 71008) isolates the machine from supply; also satisfies LOTO. \\ \hline
\S7 & Overcurrent protection & Branch and downstream fusing at terminal blocks (PSU 25 A slow-blow, PLC 1 A fast-blow, control loads individually fused). \\ \hline
\S8 & Protective bonding circuit & Continuous equipment-grounding / bonding path to all exposed conductive parts. \\ \hline
\S9 & Control circuits \& functions & Stop functions classified by stop category; the hardwired safety chain has precedence over the PLC. \\ \hline
\S10.7--10.8 & Operator interface / E-stop & Red mushroom actuator on a yellow background, self-latching NC contact; start devices guarded by the two-hand requirement. \\ \hline
\S13.2 & Conductor color coding & Black AC line/load, red AC control, blue DC control, blue/white DC return, green/yellow PE; wires labeled both ends, landed straight (no ferrules in this build). \\
\hline
\end{tabularx}
\renewcommand{\arraystretch}{1.0}

\subsection{NEMA Standards}
\label{subsec:nema}
\renewcommand{\arraystretch}{1.3}
\noindent\begin{tabularx}{\textwidth}{|p{2.5cm}|p{3.0cm}|X|}
\hline
\rowcolor{PSUgreen!12}\textbf{Standard} & \textbf{Covers} & \textbf{How it is applied here} \\
\hline
NEMA 250 & Enclosure type ratings & Targeting Type 12 (dust-tight, drip-tight) for the PLC/HMI panel. \todo{Confirm final enclosure type and dust-ingress handling.} \\ \hline
NEMA ICS 1 / ICS 2 & Industrial control \& systems & Contactor and control-device selection/marking; the Mitsubishi SD-N35 is sized above motor FLA for AC-3 (motor) duty. \\ \hline
NEMA MG 1 & Motors \& generators & Interpreting the motor nameplate (voltage, poles, RPM, service factor) for VFD parameters \texttt{PD141--PD144}. \\
\hline
\end{tabularx}
\renewcommand{\arraystretch}{1.0}

\subsection{Machine-Safety Standards (ISO / IEC)}
\renewcommand{\arraystretch}{1.3}
\noindent\begin{tabularx}{\textwidth}{|p{2.5cm}|p{3.0cm}|X|}
\hline
\rowcolor{PSUgreen!12}\textbf{Standard} & \textbf{Covers} & \textbf{How it is applied here} \\
\hline
ISO 12100 & Risk assessment / reduction & Identifies the primary hazards (rotating blades, entanglement, electrical) and drives the layered safeguards. \\ \hline
ISO 13849-1 & Safety-related control parts (PL) & Preliminary assessment: hardwired E-stop $\approx$ Cat 1; two-hand permissive $\approx$ Cat B (see the Safety Functions section). \\ \hline
ISO 13850 & Emergency stop function & Category 0 stop (immediate removal of power) with fail-safe NC wiring. \\ \hline
ISO 13851 & Two-hand control devices & Both buttons actuated within 0.5 s of each other and held continuously to enable the motor. \\ \hline
IEC 60204-1 & Electrical equipment of machines & International analogue of NFPA 79; used to cross-check stop categories and supply disconnection. \\
\hline
\end{tabularx}
\renewcommand{\arraystretch}{1.0}

\subsection{Occupational Safety (OSHA)}
\renewcommand{\arraystretch}{1.3}
\noindent\begin{tabularx}{\textwidth}{|p{2.5cm}|p{3.0cm}|X|}
\hline
\rowcolor{PSUgreen!12}\textbf{Regulation} & \textbf{Covers} & \textbf{How it is applied here} \\
\hline
29 CFR 1910.147 & Lockout/Tagout (LOTO) & The main supply disconnect is lockable for positive isolation during blade-area service and maintenance. \\ \hline
29 CFR 1910 Subpart S & Electrical safety & General electrical-safety practices (guarding of live parts, grounding) observed throughout the panel build. \\
\hline
\end{tabularx}
\renewcommand{\arraystretch}{1.0}

\todo{Before final submission: convert any remaining ``targets / intends to'' language
above into verified compliance statements, attach the panel enclosure datasheet, and
resolve the NFPA 79 neutral-switching deviation note.}

\section{Testing and Validation}

\subsection{Signal Chain Tests}
\begin{itemize}
    \item Manual jumper test (FA-FC short): confirmed PLC X5 reads LOW correctly -- wiring intact.
    \item Guaranteed-trip test (\texttt{PD124 = 1}, \texttt{PD125 = 5.0}): VFD trips reliably on motor run, fault relay fires, PLC X5 drops.
    \item Threshold tuning: 150\% (\texttt{PD124 = 150}) chosen for production based on no-load current (0.5 A) versus expected jam current (above 11 A actual).
\end{itemize}

\subsection{Load Testing}
\todo{Schedule load testing with actual plastic samples once mechanical integration complete. Need ME team coordination.}

\subsection{Safety Validation}
\begin{itemize}
    \item E-stop response time: \todo{measure with scope}.
    \item Two-hand control timing: \todo{verify both buttons must be held continuously; simultaneous release stops within X ms}.
\end{itemize}

\section{Results}

\subsection{What Works}
\begin{itemize}
    \item All motor parameters programmed and verified.
    \item Over-torque detection chain validated (VFD detects, relay fires, PLC reads, ladder reacts).
    \item Fail-safe NC wiring confirmed -- system correctly enters fault state on signal chain failure.
    \item HMI communicates with the PLC over the serial COM link.
\end{itemize}

\subsection{Open Issues}
\begin{itemize}
    \item Vendor-specific Huanyang firmware quirk: \texttt{PD052 = 12} does not fire relay in continue-running mode. Working around with \texttt{PD052 = 02} + \texttt{PD123 = 3}.
    \item PLC ladder logic not fully complete -- state machine implemented, but unjam routine timing needs tuning with real loaded motor.
    \item Mechanical integration pending -- have not yet tested under real shredding load.
    \item Motor-current monitor (VFD \texttt{VO} $\rightarrow$ F2-08AD-1 CH1) is wired, but under time constraints it was never configured/scaled correctly to read the VFD output current. The signal path exists; the VFD analog-output and PLC analog-input scaling still need to be set and calibrated.
\end{itemize}

\question{How much detail should we include about the Huanyang firmware quirk? It is an interesting design lesson (vendor lock-in, never trust the datasheet completely) but distracts from the high-level results.}

\section{Discussion}

\subsection{Design Tradeoffs}
\begin{itemize}
    \item Cost versus reliability: chose Huanyang VFD (\$150) over ATO (\$450). Firmware quirks documented in this report (the Software Design note and Appendix D) for future maintenance.
    \item 110V single-phase versus 220V split-phase mains: 110V chosen for receptacle availability in PSU lab; trade-off is double the input current and need for a dedicated 30 A circuit.
    \item NO active-high versus NC fail-safe jam signal: the VFD fault relay is wired NO active-high (FA--FC closes on trip, X5 HIGH). Simpler to wire, but not fail-safe at the signal level---a broken wire reads as ``no fault.'' That residual risk is covered by the independent hardwired E-stop loop and motor contactor, which remove power regardless of the PLC.
\end{itemize}

\subsection{Lessons Learned}
\begin{itemize}
    \item Always verify VFD relay function with multimeter before assuming firmware works as documented.
    \item Document deviations from datasheet behavior in version control so future teams can find them.
    \item Power cycle after parameter changes -- some VFDs require it for save to fully take effect.
    \item Use ferrules on control wires in future builds: this build landed straight stranded wire at the terminal blocks, and loose/spread strands caused multiple debugging hours during commissioning.
\end{itemize}

\subsection{Project Management Notes}
\todo{Add a paragraph on how the team coordinated, what tools we used (GitHub, weekly meetings, etc.), and how schedule slipped or held.}

\section{Future Work and Improvements}

\subsection{Safety and Compliance}
\begin{itemize}
    \item \textbf{Integrate the capacitive-touch safety (CTSI) module:} wire the on-hand capacitive-touch module to input X7. The ladder logic to stop the motor and raise a fault on a touch trip is already written, so this is primarily a wiring and validation task. It adds a no-contact operator-presence safeguard at the feed.
    \item \textbf{Raise the safety performance level:} move from the current single-channel Cat B--1 toward Cat 3 / PL d --- a safety relay or safety-rated PLC, dual-channel inputs, two contactors (or force-guided contacts) with feedback (EDM) monitoring, and a synchronous two-hand module per ISO 13851.
    \item \textbf{Correct the supply switching:} switch the hot (ungrounded) conductor through the contactor rather than the neutral, per NFPA 79 / NEC.
    \item \textbf{Ferrule the control wiring:} crimp ferrules on stranded control conductors at the terminal blocks to eliminate the loose-strand faults seen during commissioning.
\end{itemize}

\subsection{Monitoring and Connectivity}
\begin{itemize}
    \item \textbf{Telemetry:} stream live operating data (motor current, speed, jam count, fault state, runtime) off the PLC for dashboards and trend analysis.
    \item \textbf{Modbus to the VFD:} the Huanyang supports RS-485 Modbus (currently unused). Adding it would pull far richer data straight from the drive --- output current, voltage, frequency/RPM, DC-bus voltage, drive temperature, and detailed fault codes --- beyond the single 0--10 V analog monitor.
    \item \textbf{Internet / remote viewing:} expose a read-only view of device status over the network --- via the H2-DM1E's built-in web server or an ESP32 / edge gateway --- so the shredder can be monitored remotely from a browser or phone.
    \item \textbf{Data logging:} record total runtime, jam events per shift, and faults locally for predictive maintenance.
\end{itemize}

\subsection{Capability}
\begin{itemize}
    \item \textbf{Predictive jam detection:} train a small model on the motor-current waveform shape just before a jam to detect and pre-empt jams earlier.
    \item \textbf{Mechanical integration:} add a feed hopper that auto-meters plastic into the blades.
    \item \textbf{Higher-capacity model:} scale to a 5--10 HP drivetrain for greater throughput.
\end{itemize}

\section{Ethics and Design Considerations}

A summary of the ethics and design evaluation follows:

\begin{itemize}
    \item \textbf{Public health and safety:} Yes -- layered safety functions (hardwired E-stop, two-hand deadman control), NFPA 70 / NEMA compliance, hardwired safety chain.
    \item \textbf{Environmental:} Yes -- core project purpose is diverting plastic from landfill.
    \item \textbf{Economic:} Yes -- significant cost savings versus commercial alternatives, careful component selection within budget.
    \item \textbf{Global:} Possibly -- approach is replicable globally, components internationally sourced.
    \item \textbf{Cultural:} No -- industrial machine for B2B use, no culture-specific design.
\end{itemize}

\section{References}

\begin{itemize}
    \item NFPA 70 (2023): National Electrical Code (esp. Articles 110, 250, 310, 409, 430).
    \item NFPA 79 (2024): Electrical Standard for Industrial Machinery.
    \item NEMA 250: Enclosures for Electrical Equipment.
    \item NEMA ICS 1 / ICS 2: Industrial Control and Systems.
    \item NEMA MG 1: Motors and Generators.
    \item UL 508A: Industrial Control Panels.
    \item IEC 60204-1:2016: Safety of Machinery -- Electrical Equipment of Machines.
    \item ISO 12100:2010: Safety of Machinery -- Risk Assessment and Risk Reduction.
    \item ISO 13849-1:2023: Safety-related parts of control systems.
    \item ISO 13850:2015: Emergency Stop Function.
    \item ISO 13851:2019: Two-hand control devices.
    \item OSHA 29 CFR 1910.147: The Control of Hazardous Energy (Lockout/Tagout).
    \item Huanyang HY-series VFD User Manual.
    \item AutomationDirect DL205 / Do-more User Manual.
    \item GE 5KE Frame 182T Motor Datasheet.
\end{itemize}

\todo{Add full reference list with URLs / publication info before final.}

\section{Appendices}

\subsection{Appendix A: Bill of Materials}

The complete as-built Bill of Materials is consolidated in \texttt{BOM/BOM\_Combined\_As\_Built.xlsx}
(and the rendered \texttt{BOM/BOM\_Combined\_As\_Built.pdf}) in the project repository. The
workbook contains three sheets:

\begin{itemize}
    \item \textbf{Combined BOM} --- every item actually installed in the control panel,
      grouped by category (Motor \& Drive, Power Distribution, PLC Control System, HMI,
      Operator Controls, Motor Connections, Wire/Duct/Hardware) with manufacturer, part
      number, quantity, and notes pointing back to the relevant documentation.
    \item \textbf{Excluded - Not Used} --- items that appeared in preliminary BOMs but
      were not used in the final build, with the reason (rejected during selection,
      not purchased, superseded by another component, or out of project budget).
    \item \textbf{VFD Decision Matrix} --- the weighted comparison used to select the
      Huanyang HY02D211B-T (price 50\%, current capability 20\%, build quality 15\%,
      documentation 10\%, brand 5\%).
\end{itemize}

\textbf{Critical items} (highlighted in the workbook): Motor (GE 5KE182BC205B for bench
test), VFD (Huanyang HY02D211B-T), Brake Resistor (ATO APCS-300R30-AD), Mean Well
NDR-480-24 24V DC power supply, Mitsubishi SD-N35 contactor, Cutler-Hammer E22B1
E-stop, AutomationDirect PLC rack with H2-DM1E CPU and the D2-08ND3 / F2-08AD-1 /
F2-04RTD / D2-08TR / F2-08DA-2 modules, EA1-T4CL HMI.

\note{The bench-test motor is the GE 5KE182BC205B (3 HP, 230 V, 7.6 A, 4-pole, 1750
RPM) used to validate the control system. The final production motor remains TBD per
the 3-5 HP project requirement; its nameplate will supersede VFD parameters
\texttt{PD141}--\texttt{PD144}. Control-panel detail (rack layout, terminal-by-terminal
wiring) is itemized in the point list in Appendix B.}

\subsection{Appendix B: PLC I/O Point List}
The complete as-built point list, transcribed from the project workbook
(\texttt{Point List.xlsx}), follows on the landscape pages below --- every sheet, using
the spreadsheet's columns \emph{Point Description, Origin Address, DO / DI / AO / AI /
Pwr, Destination Address, Destination Description, and Notes}: the index; the Mitsubishi
SD-N35 contactor; the Mean Well NDR-480-24 power supply; the DirectLOGIC 205 rack and
the H2-DM1E CPU; the EA1-T4CL HMI; every I/O module (D2-08ND3, F2-08AD-1, F2-04RTD,
D2-08TR, F2-08DA-2), the legacy D2-08TA and F2-02DAS-2 sheets; and the Huanyang
HY02D211B-T VFD.

\input{appendix_pointlist}

\subsection{Appendix C: Wiring Diagrams}
\todo{Insert exported PDFs from AutoCAD: power, VFD/motor, PLC/HMI, power distribution.}

\subsection{Appendix D: VFD Parameter Settings}
The full programmed parameter set --- code, function, value, and rationale --- is given
in Table~\ref{tab:vfdparams} (Section~\ref{sec:motorvfd}, Motor and VFD). Motor values
PD141--144 reflect the GE 5KE182BC205B test motor; the production motor is TBD and its
nameplate will supersede these.

\textbf{Power / braking wiring:} R = AC hot (30 A breaker); T = AC neutral via SD-N35
contactor; U/V/W to motor via colored banana sockets; P+/PR to a 300 W, 30 $\Omega$
brake resistor (ATO APCS-300R30-AD) to absorb regenerative energy during reversal in
the jam-clear cycle. Control wiring is summarized in Appendix B.

\note{Firmware-specific finding: \texttt{PD052 = 12} (continue-running over-torque
indication) did not fire the relay on our Huanyang revision; the working configuration
is \texttt{PD052 = 02} with \texttt{PD123 = 3} (over-torque self-trips, which fires the
fault relay and is read by the PLC on X5).}

\subsection{Appendix E: Test Plan}
Test Plan v1.0 comprises a top-down power-on walkthrough followed by ten bottom-up
test cases. Each case is exercised against the must/should requirements (M-series).

\renewcommand{\arraystretch}{1.2}
\noindent\begin{tabularx}{\textwidth}{|l|X|}
\hline
\textbf{ID} & \textbf{Test case} \\
\hline
Top-down & Power-on walkthrough: AC in $\rightarrow$ PSU $\rightarrow$ PLC boot $\rightarrow$ HMI IDLE/READY \\ \hline
BU-01 & AC power input and fuse distribution \\ \hline
BU-02 & 24 VDC PSU output (Mean Well NDR-480-24) \\ \hline
BU-03 & PLC rack initialization (DirectLOGIC 205) \\ \hline
BU-04 & E-stop hardware safety circuit \\ \hline
BU-05 & Two-hand start (deadman) safety logic \\ \hline
BU-06 & Lid interlock (n/a in this build --- access guarded mechanically by the ME team) \\ \hline
BU-07 & VFD speed command and motor RPM (HY02D211B-T) \\ \hline
BU-08 & Overcurrent / overload protection \\ \hline
BU-09 & HMI operator interface (EA1-T4CL C-More Micro-Graphic) \\ \hline
BU-10 & Status indicator lights (power / running / fault) \\
\hline
\end{tabularx}
\renewcommand{\arraystretch}{1.0}

Validation results to date are summarized in the Testing and Validation and Results
sections; load testing under real shredding load is pending mechanical integration.

\newpage
\section{Authors and Acknowledgements}

\subsection*{\textcolor{PSUgreen}{Authors}}
\noindent \textcolor{PSUblue}{\textbf{Bao Nguyen}} \textbullet\ \textcolor{PSUblue}{\textbf{Fearghus Tyler}} \textbullet\ \textcolor{PSUblue}{\textbf{Yaqoub Rabiah}} \textbullet\ \textcolor{PSUblue}{\textbf{Fox Kang}}\\
{\small Department of Electrical \& Computer Engineering, Portland State University.}

\subsection*{\textcolor{PSUgreen}{Acknowledgements}}
\noindent{\small The team thanks our industry sponsor, MME / Ichor Systems, and Bridget Lannigan for project direction and support; our faculty advisors Prof. Andrew Greenberg and Dr. Jonathan Bird (Electrical) and Robert Paxton (Mechanical) for their guidance; and the Maseeh College of Engineering \& Computer Science at Portland State University for facilities and resources.}

\subsection*{\textcolor{PSUgreen}{Disclaimer}}
\noindent{\small This report documents an in-progress senior capstone design. Findings, parameters, and as-built details reflect the current state of the prototype and are subject to revision through final validation.}

\vfill
\noindent\rule{\textwidth}{0.4pt}

\noindent\textit{End of rough draft. Comments and questions welcome.}

\noindent\rule{\textwidth}{0.4pt}

\end{document}

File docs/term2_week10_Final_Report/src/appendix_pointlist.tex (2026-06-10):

% Auto-generated by gen_pointlist.py from PLC/Point_List.xlsx -- do not edit by hand.
\begingroup
\footnotesize
\setlength{\tabcolsep}{3pt}
\renewcommand{\arraystretch}{1.15}
\begin{landscape}

\noindent\textbf{\textcolor{PSUgreen}{\Large Sheet: Index}}\par\medskip
\begin{xltabular}{\linewidth}{|p{2.5cm}|X|}
\hline
\rowcolor{PSUgreen!12}\textbf{Sheet \#} & \textbf{Sheet Name} \\ \hline
1 & Mitsubishi SD-N35 \\ \hline
2 & Mean Well NDR-480-24 \\ \hline
3 & Direct Logic 205 D2-09B-1 \\ \hline
4 & DirectLOGIC CPU (H2-DM1E) \\ \hline
5 & Output Module (D2-08TA) \\ \hline
6 & HMI (EA1-T4CL) \\ \hline
7 & Output Module (F2-02DAS-2) \\ \hline
8 & Input Module (D2-08ND3) \\ \hline
9 & Analog Input (F2-08AD-1) \\ \hline
10 & RTD Input (F2-04RTD) \\ \hline
11 & Relay Output (D2-08TR) \\ \hline
12 & Analog Output (F2-08DA-2) \\ \hline
13 & VFD (Huanyang HY02D211B-T) \\ \hline
\end{xltabular}
\clearpage
\noindent\textbf{\textcolor{PSUgreen}{\Large Sheet: Index --- Revision History}}\par\medskip
\begin{xltabular}{\linewidth}{|p{4cm}|p{4cm}|p{4cm}|p{4cm}|p{4cm}|X|}
\hline
 & REV & DATE & DESCRIPTION & Created By & Checked by \\ \hline
 & 1 & 2026-03-14 & Initial point list (end of Winter term). & Bao Nguyen & Fearghus Tyler \\ \hline
 & 2 & 2026-05-18 & Updated with as-built wiring and module corrections. & Bao Nguyen & Fearghus Tyler \\ \hline
 & 3 & 2026-06-01 & Added missing component sheets to index; full revision log. & Bao Nguyen & Fearghus Tyler \\ \hline
\end{xltabular}
\clearpage

\noindent\textbf{\textcolor{PSUgreen}{\Large Sheet: Mitsubishi SD-N35}}\par\medskip
\begin{xltabular}{\linewidth}{|p{3.0cm}|p{1.25cm}|c|c|c|c|c|p{2.5cm}|p{4.0cm}|X|}
\hline
\rowcolor{PSUgreen!12}\textbf{Point Description} & \textbf{Origin} & \textbf{DO} & \textbf{DI} & \textbf{AO} & \textbf{AI} & \textbf{Pwr} & \textbf{Destination Address} & \textbf{Destination Description} & \textbf{Notes} \\
\hline
\endfirsthead
\hline
\rowcolor{PSUgreen!12}\textbf{Point Description} & \textbf{Origin} & \textbf{DO} & \textbf{DI} & \textbf{AO} & \textbf{AI} & \textbf{Pwr} & \textbf{Destination Address} & \textbf{Destination Description} & \textbf{Notes} \\
\hline
\endhead

Contactor (Mitsubishi SD-N35) -- Coil A1 & A1 & 0 & 0 & 0 & 0 & 1 & Y0 & D2-08TD2 Output Module (12--24VDC) & A1 $\rightarrow$ DF103V (1/2A slow blow fuse) $\rightarrow$ D2-08TD2 output supplying +24VDC \\ \hline
Contactor (Mitsubishi SD-N35) -- Coil A2 & A2 & 0 & 0 & 0 & 0 & 1 & -V & NDR-480-24 Power Supply & A2 $\rightarrow$ direct return to power supply negative (--V) \\ \hline
Contactor (Mitsubishi SD-N35) -- Line Input & L1 & 0 & 0 & 0 & 0 & 1 & L & Phoenix Contact TMC 83C 15A (2907618) & L1 $\rightarrow$ Phoenix Contact fuse breaker $\rightarrow$ fed from wall AC line \\ \hline
Contactor (Mitsubishi SD-N35) -- Load Output & T1 & 0 & 0 & 0 & 0 & 1 & R & HY Series VFD (HY02D211B-T) & T1 $\rightarrow$ passes through contactor $\rightarrow$ supplies VFD terminal R (line input) \\ \hline
\rowcolor{PSUgreen!12}\textbf{Total Points} &  & \textbf{0} & \textbf{0} & \textbf{0} & \textbf{0} & \textbf{4} &  &  &  \\ \hline
\end{xltabular}
\clearpage

\noindent\textbf{\textcolor{PSUgreen}{\Large Sheet: Mean Well NDR-480-24}}\par\medskip
\begin{xltabular}{\linewidth}{|p{3.0cm}|p{1.25cm}|c|c|c|c|c|p{2.5cm}|p{4.0cm}|X|}
\hline
\rowcolor{PSUgreen!12}\textbf{Point Description} & \textbf{Origin} & \textbf{DO} & \textbf{DI} & \textbf{AO} & \textbf{AI} & \textbf{Pwr} & \textbf{Destination Address} & \textbf{Destination Description} & \textbf{Notes} \\
\hline
\endfirsthead
\hline
\rowcolor{PSUgreen!12}\textbf{Point Description} & \textbf{Origin} & \textbf{DO} & \textbf{DI} & \textbf{AO} & \textbf{AI} & \textbf{Pwr} & \textbf{Destination Address} & \textbf{Destination Description} & \textbf{Notes} \\
\hline
\endhead
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

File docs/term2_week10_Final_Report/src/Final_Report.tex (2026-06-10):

\documentclass[hidelinks,12pt]{article}
\usepackage[utf8]{inputenc}

\usepackage[letterpaper, margin=1in]{geometry}
\usepackage{graphicx}
\usepackage{float}
\usepackage[labelfont=bf]{caption}
\usepackage{setspace}
\usepackage{fancyhdr}
\usepackage{enumitem}
\usepackage{hyperref}
\usepackage{xcolor}
\usepackage{titlesec}
\usepackage{tcolorbox}
\usepackage{colortbl}
\usepackage{booktabs}
\usepackage{parskip}
\usepackage{tabularx}
\usepackage{xltabular}
\usepackage{tikz}
\usepackage{pdfpages}
\usepackage{pdflscape}
\usepackage{newunicodechar}
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

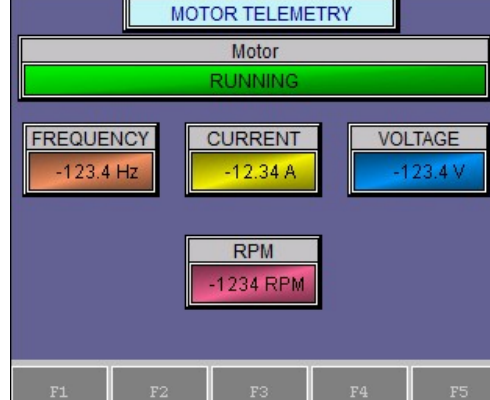
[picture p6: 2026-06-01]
docs/term2_week10_Final_Report/src/images/hmi_screen_2_motor_telemetry.png

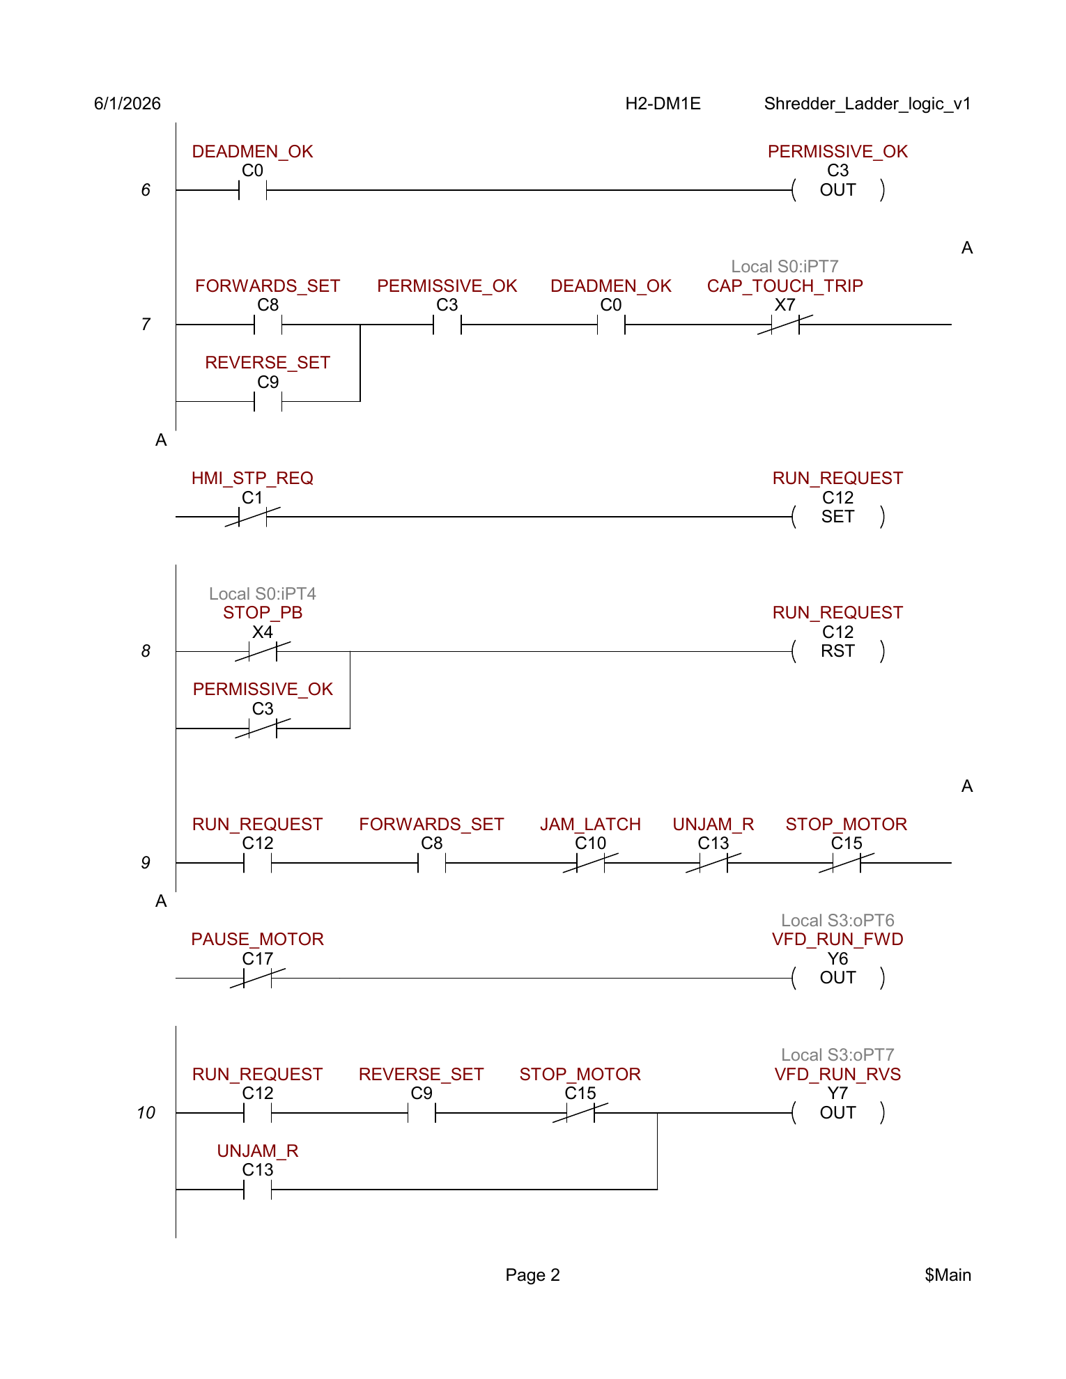
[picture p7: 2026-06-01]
docs/term2_week10_Final_Report/src/images/rung_page-2.png

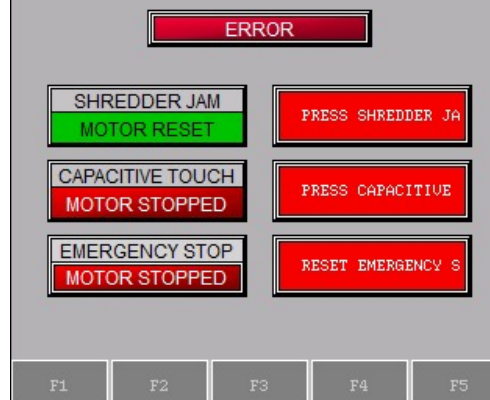
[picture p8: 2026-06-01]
docs/term2_week10_Poster/src/Pictures/HMI_Error.png

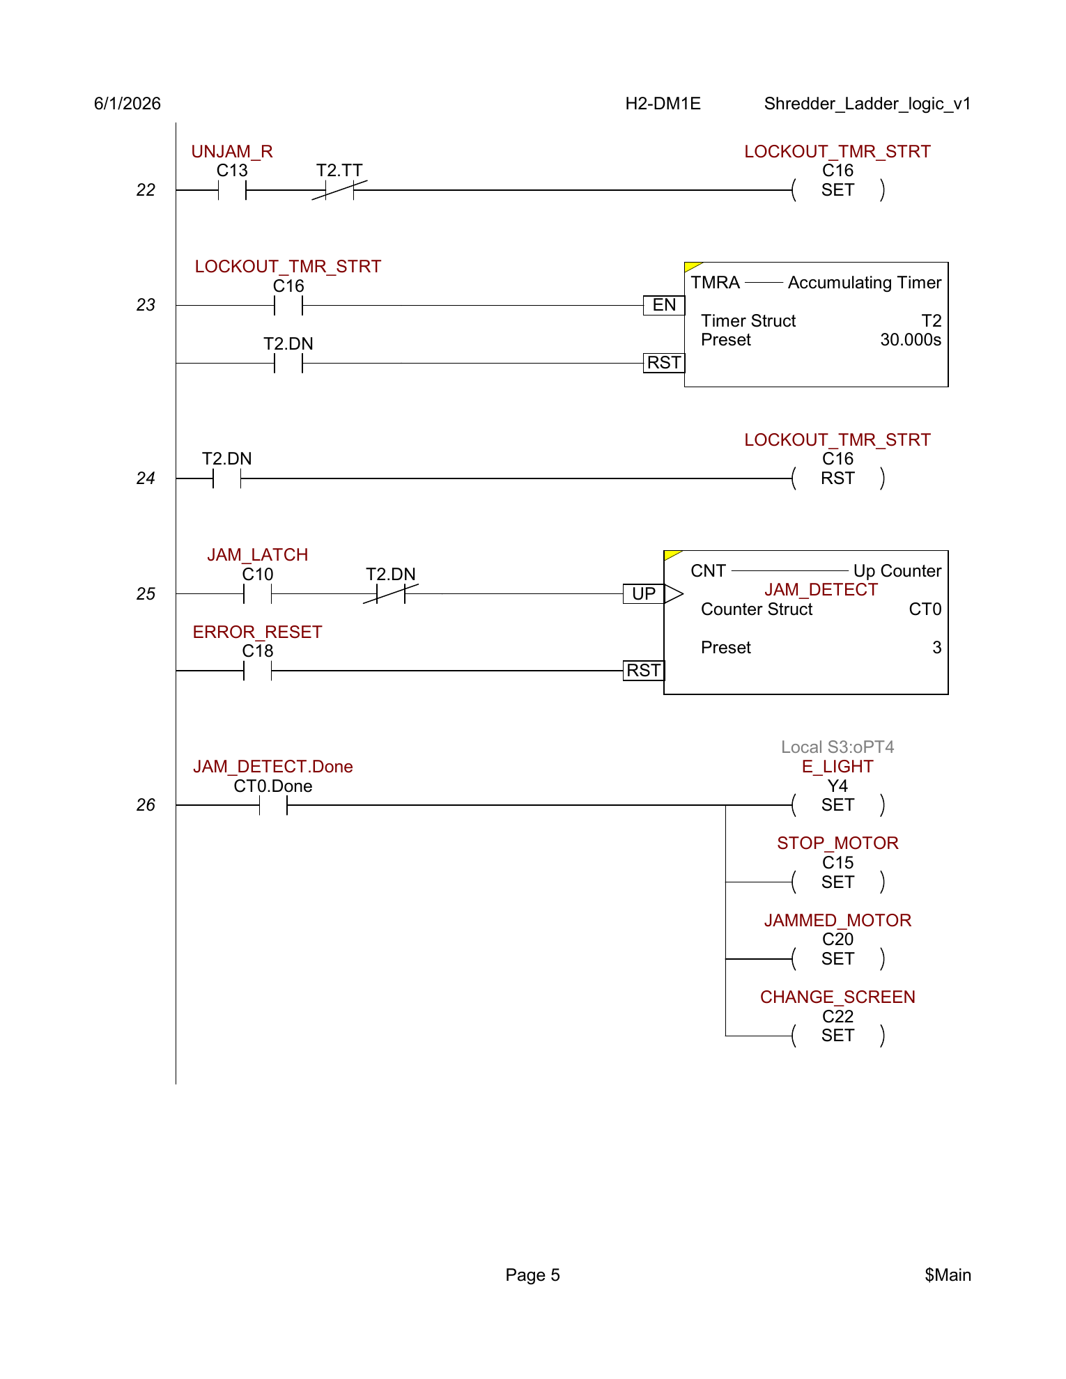
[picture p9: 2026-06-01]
docs/term2_week10_Poster/src/Pictures/Ladder_5.png

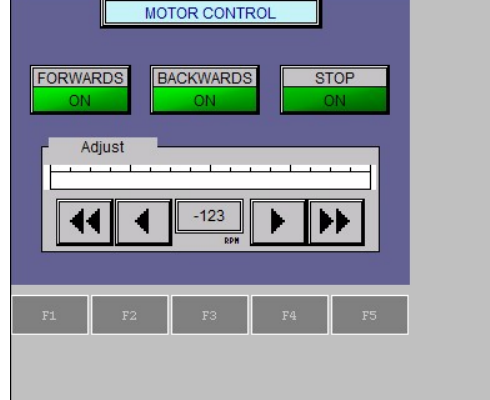
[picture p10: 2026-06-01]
docs/term2_week10_Poster/src/Pictures/HMI_Motor_Control.png

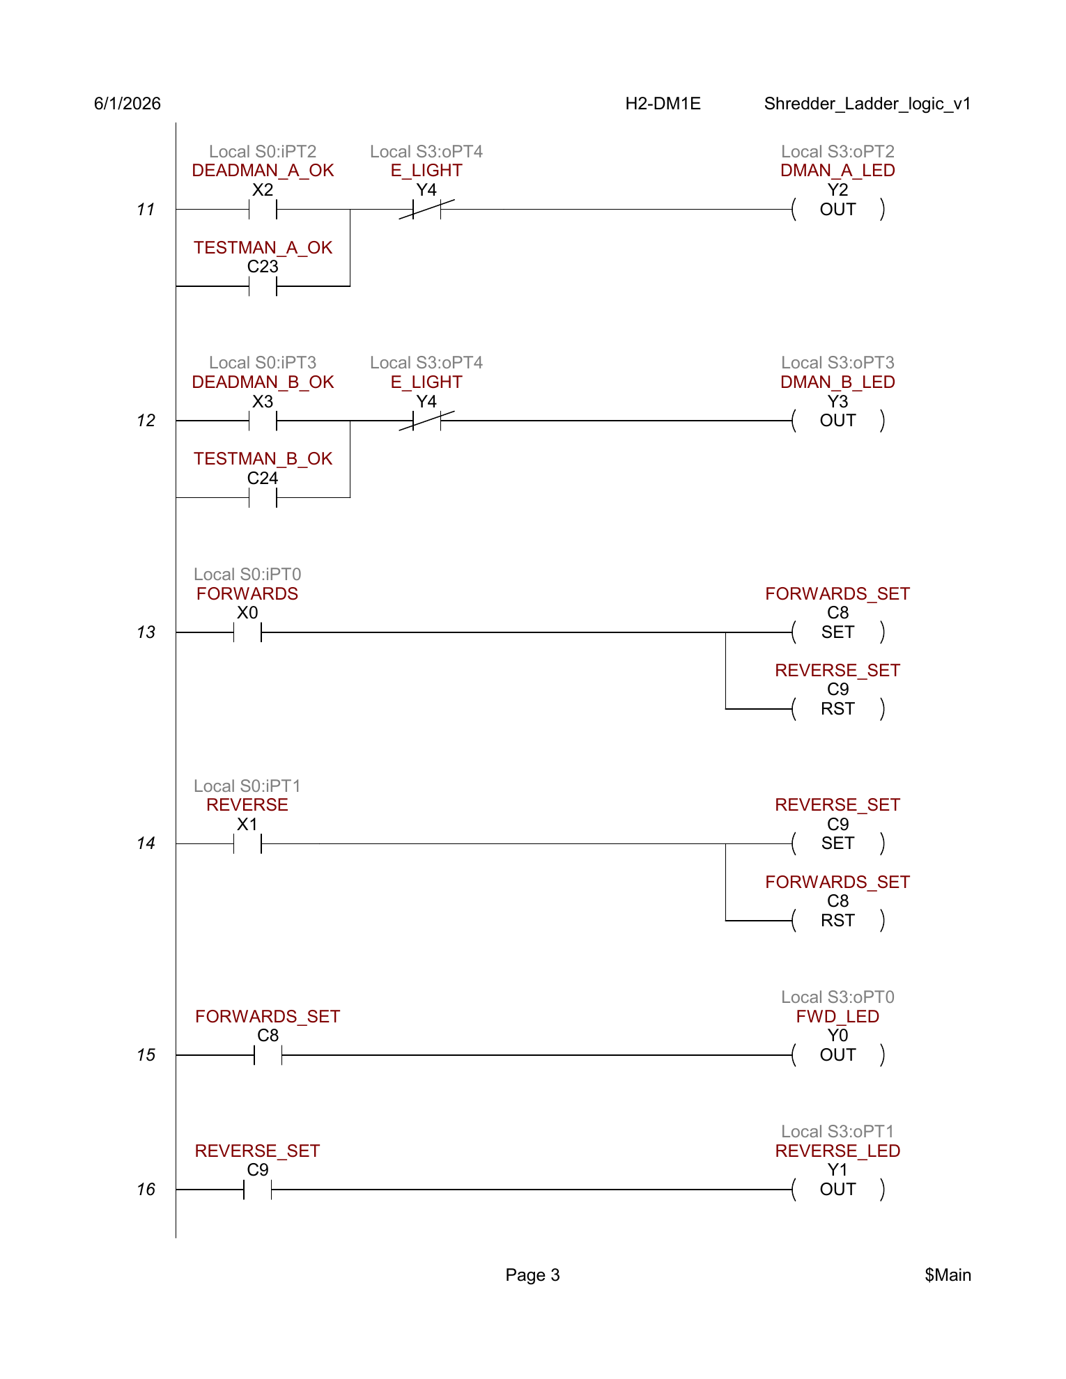
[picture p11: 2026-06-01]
docs/term2_week10_Final_Report/src/images/rung_page-3.png

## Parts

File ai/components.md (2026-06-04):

# Hardware Components

## PLC System
| Component | Model | Notes |
|---|---|---|
| PLC Rack | DirectLOGIC 205 D2-09B-1 | 9-slot base unit |
| CPU | H2-DM1E | Built-in Ethernet, executes ladder logic |
| Discrete Input | D2-08ND3 | 8-ch 24VDC digital inputs, sourcing (Slot 2) |
| Analog Input | F2-08AD-1 | 8-ch current input 4–20mA; CH1 = VFD VO motor-current monitor (Slot 3) |
| RTD Input | F2-04RTD | 4-ch PT100/PT1000 temp, all channels spare (Slot 4) |
| Relay Output | D2-08TR | 8-ch relay (dry contact), sinking, common to PSU −V (Slot 5) |
| Analog Output | F2-08DA-2 | 8-ch voltage output 0–10V; CH1 = VFD VI speed reference (Slot 6) |
| Fill Panels | D2-Fill | Slots 7, 8, 9 (reserved) |

## HMI
| Component | Model | Notes |
|---|---|---|
| Touch Panel | EA1-T4CL | 4" C-More Micro-Graphic color touch panel |
| HMI Power | Mean Well NDR-480-24 | Runs on the shared 24VDC supply (replaces former Rhino PSB12-030-P) |
| PLC–HMI Link | Serial (CPU COM port) | Match baud/parity/stop bits on both ends |

## Power
| Component | Model | Notes |
|---|---|---|
| 24VDC Power Supply | Mean Well NDR-480-24 | Powers PLC I/O, contactor coil, pushbutton commons |
| Fuse Block (main) | MORSETTITALIA EURO S10H-5H | 25A for PSU branch, 1A for PLC branch |
| Pushbutton fuse | MORSETTITALIA EURO S4LH | 1A fast blow, distributed to pushbutton commons |

## Motor Control
| Component | Model | Notes |
|---|---|---|
| VFD | Huanyang HY02D211B-T | 0–10V speed command via F2-08DA-2 +V1 → VFD VI; current monitor via VFD VO → F2-08AD-1 CH1 |
| Motor | IronHorse MTCP2-002 | 2 HP, 230 V low-voltage / 5.93 A FLA / 4-pole / 1735 RPM, NEMA 145TC TEFC IP55, VFD-rated 1.0 SF. Motor leads via colored 4mm banana sockets (U=blue, V=white, W=red) to T1/T2/T3. Bench bring-up used a GE 5KE182BC205B; see `VFD/Motor_Nameplate.md` for the historical reference. |
| Contactor | Mitsubishi SD-N35 | Coil A1 in E-stop safety chain (E22B1 NC → A1, A2 → PSU −V); switches VFD T (neutral) leg |
| Line breaker | Phoenix Contact TMC 8 3C 15A (2907618) | Feeds SD-N35 contactor pole on the VFD neutral leg |
| Brake Resistor | ATO APCS-300R30-AD | 300W, 30Ω dynamic braking resistor on VFD P+/PR |
| Error Indicator | Wamco model 525 | Panel LED (28VDC, 0.6W) driven by D2-08TR Y4 |

## Safety / Control
| Component | Notes |
|---|---|
| E-stop | Hardwired NC into safety circuit |
| Two-hand start | Forward + Deadman SW1 + Deadman SW2 buttons (24VDC, fused 1.5A) |
| Lid interlock | DI input to PLC |
| Status lights | Power on / Running / Fault (driven by discrete outputs) |

## Wiring Accessories
| Component | Model | Notes |
|---|---|---|
| ZipLink Terminal Block | ZL-RTB20-OUT | Output module field wiring interface |
| ZipLink Terminal Block | ZL-RTB20 | Analog output field wiring interface |
| Contactor fuse | DF103V 1/2A slow blow | Protects contactor coil branch |
| Power conductor | 12 AWG Cu (THHN/MTW) | Rated 20A/25A/30A at 60/75/90 °C (NEC 310.16); used for VFD branch and power runs (IronHorse motor FLA 5.93 A; well within 12 AWG ampacity) |
| Control conductor | 16–18 AWG Cu | 24 VDC discrete/analog signal wiring; ferruled at terminal blocks |

## Overcurrent Sizing Convention
- Branch/component **fuses sized at 125% of the protected component's rated continuous load** (NEC 210.20(A)/215.3).
- Exception: the VFD motor branch breaker (30A C-curve) follows NEC 430.52 (higher multiple of FLC to ride through inrush); running overload is handled by the VFD's electronic motor-overload function.

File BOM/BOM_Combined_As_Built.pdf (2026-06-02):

PRODUCT NAME | Shredder | EE TEAM
APPROVED BY | | Fearghus Tyler
DATE OF APPROVAL | 2026-06-01 | Bao Nguyen
PART COUNT | | 62 Yaqoub Rabiah
TOTAL COST | | $969.88 Fox Kang
PART NUMBER | PART NAME | DESCRIPTION | QUANTITY | UNITS | LINK | UNIT COST | AMOUNT
5KE182BC205B | AC Motor (3 HP) | GE 3-phase TEFC induction motor; 230 V (low-voltage), 1750 RPM, 7.6 A FLA, NEMA 182T frame. Bench-test motor. | 1 | EA | https://www.electricmotorsforless.com/ | $0.00 | $0.00
HY02D211B-T | VFD | Huanyang variable frequency drive, 110 V single-phase input, 220 V 3-phase output, 2.2 kW (3 HP). Selected via decision matrix. | 1 | EA | https://www.amazon.com/Huanyang-1-Phase-Variable-Frequency-Output-3hp/dp/B0DMF3GB38 | $200.00 | $200.00
APCS-300R30-AD | Brake Resistor | LS Electric 300 W, 30 ohm aluminum-clad braking resistor for VFD dynamic braking on P+/PR. Purchased from AutomationDirect. Note: an earlier identical-part-number unit (ATO branded) was ordered but never arrived after shipping; replaced with this LS Electric unit which is the brake resistor actually installed. | 1 | EA | https://www.automationdirect.com/adc/shopping/catalog/motion_control/ls_electric_l7c_(l7ca_series)_servo_systems /servo_accessories/apcs-300r30-ad | $29.00 | $29.00
71008 | Main Power Switch | Powertec 120 V ON/OFF main disconnect switch for entire control panel. | 1 | EA | https://powertecproducts.com/71008/ | $15.00 | $15.00
TMC 8 3C 15A (2907618) | VFD Branch Breaker | Phoenix Contact thermal-magnetic DIN-rail circuit breaker, 15 A, on VFD neutral leg (per as-built). Obtained at no cost from the PSU EPL free pile. | 1 | EA | https://www.phoenixcontact.com/ | $0.00 | $0.00
NDR-480-24 | 24 VDC Power Supply | Mean Well 480 W, 24 VDC DIN-rail power supply for PLC, HMI, indicator LEDs, and VFD control loops. Donated by sponsor / obtained at no cost to the EE team. | 1 | EA | https://www.meanwell.com/ | $0.00 | $0.00
SD-N35 | Main Power Contactor | Mitsubishi 3-pole magnetic contactor. Energized through E-stop chain via E22B1 NC contact. | 1 | EA | https://www.ebay.com/itm/... (tpmachinery seller, order 23-14145-39817, Jan 2026) | $12.59 | $12.59
EURO S4LH | Fuse Block (button common) | Morsettitalia fuse-holder terminal block. Holds 1 A fast-blow fuse protecting the shared pushbutton +24 V supply. | 1 | EA | https://www.morsettitalia.com/ | $8.00 | $8.00
EURO S10H-5H | Fuse Block (AC branches) | Morsettitalia fuse-holder terminal block for AC branch protection. | 1 | EA | https://www.morsettitalia.com/ | $12.00 | $12.00
H2-DM1E | PLC CPU / Ethernet | AutomationDirect Do-more CPU with built-in Ethernet, fits D2-09B-1 DL205 rack. Purchased Jan 2026 from planet-surplus as a USED combo for $350 total, includes: D2-09B-1 chassis, D2-08ND3, F2-08AD-1, F2-04RTD, D2-08TR, F2-08DA-2, and D2-FILL filler panels. | 1 | EA | https://www.ebay.com/itm/... (planet-surplus seller, order 20-14113-87209, Jan 2026) | $350.00 | $350.00
D2-09B-1 | PLC Base / Rack | AutomationDirect DirectLOGIC 205 9-slot AC-powered base. Included in the H2-DM1E used combo purchase. | 1 | EA | https://www.automationdirect.com/ | $0.00 | $0.00
D2-08ND3 | Discrete Input Module | AutomationDirect 8-ch, 24 VDC, sourcing/sinking discrete input module. Slot 2. Inputs X0-X7. Included in the H2-DM1E used combo purchase. | 1 | EA | https://www.automationdirect.com/ | $0.00 | $0.00
F2-08AD-1 | Analog Input Module | AutomationDirect 8-ch, 4-20 mA analog current input module. Slot 3. CH1+ reads VFD VO current monitor. Included in the H2-DM1E used combo purchase. | 1 | EA | https://www.automationdirect.com/ | $0.00 | $0.00
F2-04RTD | RTD Input Module | AutomationDirect 4-ch RTD input module. Slot 4. Installed but unused (spare). Included in the H2-DM1E used combo purchase. | 1 | EA | https://www.automationdirect.com/ | $0.00 | $0.00
D2-08TR | Relay Output Module | AutomationDirect 8-ch relay output module. Slot 5. Drives button LEDs (Y0-Y4) and VFD FOR/REV/RST (Y6/Y7/Y5). Included in the H2-DM1E used combo purchase (eBay listing showed D2-08TD2 but seller substituted D2-08TR which is what we use). | 1 | EA | https://www.automationdirect.com/ | $0.00 | $0.00
F2-08DA-2 | Analog Output Module | AutomationDirect 8-ch, 0-10 V analog voltage output module. Slot 6. +V1 drives VFD VI speed reference. Included in the H2-DM1E used combo purchase (eBay listing showed F2-02DA but actual unit is F2-08DA-2). | 1 | EA | https://www.automationdirect.com/ | $0.00 | $0.00

PART NUMBER | PART NAME | DESCRIPTION | QUANTITY | UNITS | LINK | UNIT COST | AMOUNT
D2-FILL | Rack Filler Panels | AutomationDirect blank fill panels for unused rack slots 7-9. Included in the H2-DM1E used combo purchase. | 3 | EA | https://www.automationdirect.com/ | $0.00 | $0.00
EA1-T4CL | HMI Touch Panel | AutomationDirect C-More Micro-Graphic 4-inch color touch panel HMI. Purchased used from eBay for $148.95 (Apr 2026). Purchase included the serial cable for HMI-to-CPU communication (RS-232 to H2-DM1E serial port). | 1 | EA | https://www.ebay.com/itm/306662618920 | $148.95 | $148.95
S2PR-P3G | Forward Pushbutton Head | Autonics 22 mm illuminated green pushbutton head (Forward command -> X0). | 1 | EA | https://www.autonics.com/us/model/S2PR-P3GAD | $1.90 | $1.90
S2PR-P3Y | Reverse Pushbutton Head | Autonics 22 mm illuminated yellow pushbutton head (Reverse command -> X1). | 1 | EA | https://www.autonics.com/us/model/S2PR-P3YAD | $1.90 | $1.90
S2PR-P3B | Run/Deadman Pushbutton Head | Autonics 22 mm illuminated blue pushbutton head (Run 1 -> X2, Run 2 -> X3). | 2 | EA | https://www.autonics.com/us/model/S2PR-P3BAD | $1.90 | $3.80
S2PR-P3R | Reset Pushbutton Head | Autonics 22 mm illuminated red pushbutton head (planned Reset -> X6). | 1 | EA | https://www.autonics.com/us/model/S2PR-P3RAD | $4.50 | $4.50
SA-CA | NO Contact Block (1NO) | Autonics finger-safe 1NO contact block. 110 VAC/10 A. Used with each S2PR pushbutton. | 5 | EA | https://www.autonics.com/us/model/SA-CA | $2.80 | $14.00
SA-LDG | LED Block - Green (24 VDC) | Autonics modular LED indicator block, green, 12-24 VDC. Forward button illumination -> Y0. | 1 | EA | https://www.autonics.com/us/model/SA-LDG | $4.50 | $4.50
SA-LDY | LED Block - Yellow (24 VDC) | Autonics modular LED indicator block, yellow, 12-24 VDC. Reverse button illumination -> Y1. | 1 | EA | https://www.autonics.com/us/model/SA-LDY | $4.50 | $4.50
SA-LDB | LED Block - Blue (24 VDC) | Autonics modular LED indicator block, blue, 12-24 VDC. Run 1 and Run 2 illumination -> Y2, Y3. | 2 | EA | https://www.autonics.com/us/model/SA-LDB | $4.50 | $9.00
SA-LDR | LED Block - Red (24 VDC) | Autonics modular LED indicator block, red, 12-24 VDC. Reset button illumination (planned). | 1 | EA | https://www.autonics.com/us/model/SA-LDR | $4.50 | $4.50
E22B1 | Emergency Stop Pushbutton | Cutler-Hammer / Eaton 22 mm mushroom E-stop, NC contact. In series with SD-N35 contactor coil. | 1 | EA | https://www.eaton.com/ | $25.00 | $25.00
Wamco 525 | Fault Indicator Light | Wamco panel-mount LED indicator, 28 VDC, 0.6 W. Driven by PLC Y4 as machine-fault indicator. | 1 | EA | https://www.wamco.com/ | $15.00 | $15.00
Banana Socket (Blue) | Banana Socket Blue | Generic 4 mm panel-mount banana socket, blue. Quick-disconnect for VFD U output to motor T1. Obtained at no cost from a free pile. | 1 | EA | | $0.00 | $0.00
Banana Socket (White) | Banana Socket White | Generic 4 mm panel-mount banana socket, white. VFD V output to motor T2. Obtained at no cost from a free pile. | 1 | EA | | $0.00 | $0.00
Banana Socket (Red) | Banana Socket Red | Generic 4 mm panel-mount banana socket, red. VFD W output to motor T3. Obtained at no cost from a free pile. | 1 | EA | | $0.00 | $0.00
G1X1LG6 | Slotted Wire Duct, 1"x1" | Panduit Type G wide-finger slotted PVC duct, light gray, 6 ft lengths. | 6 | FT | https://www.panduit.com/ | $3.43 | $20.58
C1LG6 | Duct Cover, 1"W | Panduit duct cover for G1X1LG6, light gray, 6 ft lengths. | 6 | FT | https://www.panduit.com/ | $1.20 | $7.20
18 AWG Blue | Control Wire, Blue | 18 AWG stranded blue control wire (NFPA 79 §13.2 DC control). Obtained at no cost (some from team member's existing stock, some from free pile). | 1 | Roll | | $0.00 | $0.00
18 AWG White | Control Return Wire | 18 AWG stranded white wire for DC return (NFPA 79 §13.2). Obtained at no cost (some from team member's existing stock, some from free pile). | 1 | Roll | | $0.00 | $0.00
12 AWG Black | Power Wire, Black | 12 AWG black wire for AC mains and motor leads. Obtained at no cost (some from team member's existing stock, some from free pile). | 1 | Roll | | $0.00 | $0.00
12 AWG Green/Yellow | Ground Wire | 12 AWG green/yellow stranded equipment grounding wire (NFPA 79). Obtained at no cost (some from team member's existing stock, some from free pile). | 1 | Roll | | $0.00 | $0.00
GMA-500mA or 0217.500MXP | Fuse - 500 mA F | Bussmann or Littelfuse 5x20 mm fast-blow fuse, 500 mA, 250 V. (Currently not installed per as-built note - retained as recommended addition.) | 1 | EA | | $1.50 | $1.50
GMA-1A or equiv. | Fuse - 1 A F | 5x20 mm fast-blow fuse, 1 A, 250 V. Protects shared +24 V pushbutton common (in EURO S4LH). | 1 | EA | | $1.50 | $1.50
| LM2596 | DC-DC Buck Converter (24V to 5V/3.3V) | Seloky LM2596-based adjustable DC-DC buck converter module with voltmeter display (sold as 2-pack). Steps down 24 VDC panel supply to the input voltage required by the capacitive touch module. | 1 | Pack | https://www.amazon.com/Converter-Adjustable-Regulator-Voltmeter-Display/dp/B0F1M2SR31 | $7.99 | $7.99

PART NUMBER | PART NAME | DESCRIPTION | QUANTITY | UNITS | LINK | UNIT COST | AMOUNT
SEB001 | Control Panel Enclosure | Vorksmen industrial control enclosure (steel) housing the entire electrical system including PLC rack, VFD, contactor, PSU, terminal blocks, and operator panel. | 1 | EA | https://www.amazon.com/ | $59.98 | $59.98
AE14921a | 3V Relay | AEDIKO 3 VDC PCB-mount relay. Used in the capacitive touch module sub-circuit to interface the low-voltage touch sensor output with the 24 VDC panel control voltage. | 1 | EA | https://www.amazon.com/ | $6.99 | $6.99
DGN-001 | Bao's Dignity | Lost on the procurement loop after lowballing roughly every vendor between Portland and Beaverton. Quoted "open-box" / "educational discount" / "the next one is on us" until even PowerTec stopped replying. Non-returnable. Replacement TBD; budget is hopefully zero. | 1 | EA | | $0.00 | $0.00
| | TOTAL PARTS | 62 | | TOTAL | | $969.88

PART NUMBER | PART NAME | DESCRIPTION | FROM BOM FILE | REASON NOT USED
PE145TC-2-4 | Motor (alternate) | Original BOM candidate motor | BOM_02_20_26 | Not used; GE 5KE182BC205B used instead for bench testing
NBE7 | Circuit Breaker | Original BOM candidate breaker | BOM_1_29 / BOM_02_20_26 | Never purchased; replaced by Phoenix Contact TMC 8 3C 15A
(30 A fuse, TBD) | 30 A Branch Fuse | Per old BOM, 2x 30 A fuses budgeted | BOM_1_29 | Never needed in final design
1866-1441-ND | DC Power Supply | 120/24 VDC PSU from Digi-Key | BOM_1_29 | Superseded by Mean Well NDR-480-24
(generic) | VEVOR 3HP 120V VFD | Hobby-grade VFD option | VFD_120V_3HP_Decision_Matrix | Rejected during selection (hobby-grade, limited documentation)
(generic) | ATO 3HP 120V VFD | Higher-quality VFD option | VFD_120V_3HP_Decision_Matrix | Too expensive ($450-500) for project budget
(generic) | 110V 20A 3HP VFD | Mid-tier VFD option | VFD_120V_3HP_Decision_Matrix | Huanyang HY02D211B-T selected instead
(WEG single-phase 3HP) | WEG Single Phase Motor | 1-phase general purpose 3 HP motor | Motor Spec | Considered but GE 5KE182BC205B used
NT3-18-213T | Worldwide Electric Motor | 3-phase TEFC 3 HP motor | Motor Spec | Considered but not purchased
(VEVOR 5HP 230V) | VEVOR High Torque Motor | 5 HP 1-phase compressor-style motor | Motor Spec | Considered but not purchased
L510 (2HP / 3HP) | TECO L510 VFD | VFD comparison option | Motor Spec | Considered but Huanyang selected
G0532 | Marathon Gearmotor | Integrated gearbox motor | Motor Spec | Considered but not purchased
KBWC-15K | KB Electronics speed control | Triac speed control fan-style | Motor Spec | VFD approach used instead
TTP223B | Capacitive Touch Sensor | Single-channel cap touch | BOM_1_30_beta (safety draft) | Does not meet industrial standards
CAP1293-1-SN | Capacitive Touch Chip | 3-channel cap touch chip | BOM_1_30_beta (safety draft) | Chip only; needs interface board
1864-1032-ND | Capacitive Proximity Sensor | Cap proximity sensor | BOM_1_30_beta (safety draft) | Too expensive ($109.25)
F3S-TGR-NMPC-21-10 | Omron Magnetic Safety Sensor | Non-contact magnetic safety switch | BOM_1_30_beta (safety draft) | Too expensive; out of stock
RSS 36-I2-D-R-ST5 | Schmersal RFID Safety Sensor | RFID safety sensor | BOM_1_30_beta (safety draft) | Suspected industrial-only / non-retail
F3SG-SR / PG | Omron Safety Light Curtain | Safety light curtain | BOM_1_30_beta (safety draft) | Out of scope for capstone budget
(Ichor-provided) | Red/Green Indicator Lights | Sponsor-provided lights | BOM_02_20_26 | Not used; Wamco 525 fault light and button LEDs cover indication
(Ichor-provided) | E-stop Pushbutton | Sponsor-provided E-stop | BOM_02_20_26 | Replaced with Cutler-Hammer/Eaton E22B1 procured by team
V30AE000055 | Insulated Ferrules, 12 AWG (gray) | Z+F crimp ferrules, 12 AWG, 10 mm length, gray (DIN color code). 500-piece pack. | URS Electronics invoice (purchased but not used) | Purchased from URS Electronics but ultimately not used in the as-built panel. Spare stock retained for future projects.

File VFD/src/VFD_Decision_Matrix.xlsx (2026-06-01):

Option | Price Score (50%) | Current Capability (20%) | Build Quality (15%) | Documentation / Support (10%) | Brand / Reliability (5%) | Total Score | Notes
VEVOR 3HP 120V VFD | 9 | 6 | 5 | 4 | 4 |  | Lowest cost ($70-95). Hobby-grade, limited docs.
110V 20A 3HP VFD (generic) | 8 | 7 | 6 | 5 | 5 |  | Best balance ($130-150). Good for 20A circuits.
Huanyang 3HP VFD (HY02D211B-T) - SELECTED | 7 | 7 | 6 | 5 | 5 |  | Common CNC choice ($120-200). Selected for project.
ATO 3HP 120V VFD | 5 | 9 | 8 | 7 | 7 |  | Higher quality but too expensive ($450-500).

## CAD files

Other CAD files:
electrical/Power_Distribution_Capstone.dwg
electrical/VFD_and_Motor.dwg
electrical/PLC_and_HMI.dwg
electrical/M01_Power.dwg

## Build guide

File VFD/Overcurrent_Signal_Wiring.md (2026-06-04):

# Overcurrent (Jam) Signal Wiring

This document describes how the VFD's over-current detection output is wired into the PLC so the control logic can detect a jam, run the auto-clear routine (RST + forward/reverse cycling), and lock out after three attempts within a single operator session.

## Background and Design Notes

The original design called for the VFD to fire an "over-torque alarm" relay while continuing to run, so the PLC could handle the unjam routine without the VFD itself tripping. This proved not to work on the specific Huanyang HY02D211B-T firmware revision used in this build: setting the relay to function `12` (Over-torque Detect) with `PD123 = 2` (continue running) does not actuate the relay coil at all. Only when the VFD self-trips does the relay fire.

The working configuration documented here uses the relay's **Fault Indication** function (`PD052 = 02`) combined with `PD123 = 3` (stop motor on over-torque detected). The over-torque condition triggers a `dT` fault, the VFD trips, the fault relay fires, and the PLC reads the trip and runs the unjam routine. This adds the requirement that the PLC must pulse the VFD's `RST` input to clear the fault between retry attempts, but the end-to-end behavior is functionally equivalent to the original design.

## VFD Relay Terminals (FA, FB, FC)

The VFD exposes three terminals for one internal SPDT relay:

| Terminal | Role | Behavior | Used? |
|---|---|---|---|
| **FA** | **F**orm **A** contact, Normally Open (NO) | Open when idle, closes when the relay energizes | **Yes — wired to +24V through fuse** |
| FB | **F**orm **B** contact, Normally Closed (NC) | Closed when idle, opens when the relay energizes | No — left empty |
| **FC** | **F**orm **C** common, the shared armature pole | Always one end of the circuit; the other end is FA or FB | **Yes — wired to PLC X5** |

Definitions:
- *Form A* = SPST normally open contact
- *Form B* = SPST normally closed contact
- *Form C* = SPDT changeover contact (NO + NC + common in one device — this is the kind the VFD has)

We use the **NO contact pair (FC + FA)** so the PLC sees an active-high signal when the VFD trips on a fault. PLC ladder logic reads `[ X5 ]` directly (no inversion needed) to detect a jam.

The NC alternative (FC + FB, fail-safe) was considered but not chosen for this build. NC wiring would require a 5-second startup mask in the ladder logic to prevent boot-time false trips, and the current setup uses redundant safety paths (hardwired E-stop loop, motor contactor) that handle wire-break failures at the safety-circuit level rather than depending on the jam signal.

## VFD Digital Input Mode (Sinking / NPN)

The VFD's digital control inputs (FOR, REV, RST) are configured for **sinking (NPN) input mode**. This means the VFD has internal pull-ups on these inputs, and they activate when the input is externally pulled down to DCM (0V). The PLC's D2-08TR relay output module (with relay common wired to PSU `-V`) drives these inputs by closing a relay contact that completes the path from the input pin to DCM.

This is opposite of the sourcing (PNP) topology where the PLC would push +24V to activate the inputs. Both topologies are valid; the choice depends on the output module type. For the D2-08TR with common on `-V`, sinking input mode is the correct match.

## Fuse Sizing (500 mA, Fast-Blow)

A 500 mA fast-blow fuse is installed in series with the +24V wire feeding the VFD's FA terminal.

The NEC 125% rule (Article 430) applies to motor branch circuits; for low-current signal circuits like this one, the fuse is sized to satisfy three constraints:

1. **Well above normal load to avoid nuisance trips.** The D2-08ND3 input draws ~8.5 mA at 24V. A 500 mA fuse provides ~60× headroom.
2. **Well below the lowest-rated downstream component.** The VFD relay contact is rated 3 A @ 250 VAC; signal wire (18 AWG) is rated ~10 A. A 500 mA fuse will open long before either is stressed.
3. **A commonly stocked standard size.** 500 mA fast-blow is a standard 5×20 mm glass fuse value.

Fast-blow (F) type is correct here. Slow-blow (T) is for inrush loads (motors, capacitive supplies); this is a steady-state signal circuit.

Suggested part numbers:
- Bussmann GMA-500mA (fast-blow, 5×20 mm)
- Littelfuse 0217.500MXP (fast-blow, 5×20 mm)

## D2-08ND3 Input Module Connection

The jam signal lands on input **X5** of the D2-08ND3 discrete input module (Slot 2).

The module is wired in **sourcing mode** (input common `C` to PSU `-V`), so each input pin reads HIGH (logic ON) when +24V is applied.

With the FA+FC (NO) wiring (+24V on FA, signal out FC to X5):
- Relay idle (no fault): FA-FC open → no +24V at X5 → **X5 = LOW** ("no jam")
- Relay energized (fault): FA-FC closed → +24V flows FA → FC → X5 → **X5 = HIGH** ("jam detected")

PLC ladder reads `[ X5 ]` to detect jam events (no inversion).

## Wire Colors and Gauge

Per **NFPA 79 §13.2**:

| NFPA 79 wire class | Color | Used for |
|---|---|---|
| AC line / load power | Black | Mains, motor leads |
| AC control circuits | Red | 120 VAC control (none used here) |
| **DC control circuits (ungrounded)** | **Blue** | **+24 VDC and all DC signal wires** |
| **DC control circuits (grounded return)** | **Blue with white stripe** | **0 VDC return / common** |
| Foreign voltage | Yellow | (none used here) |
| Equipment grounding | Green or Green/Yellow | Chassis ground |

Solid white is widely accepted in practice for DC return when Blue/W stripe is not stocked.

**Wire gauge: 18 AWG stranded with ferrules** at all terminal ends. 18 AWG is standard for control and signal wiring in industrial panels.

## Wiring Tables

### Jam Signal (VFD relay → PLC input)

| From | To | Wire color | Wire label |
|---|---|---|---|
| Mean Well +V (PSU) | 500 mA fast-blow fuse (input side) | Blue | `+24V` |
| 500 mA fuse (output side) | VFD `FA` terminal | Blue | `+24V-JAM` |
| VFD `FC` terminal | PLC `X5` (D2-08ND3 Slot 2) | Blue | `JAM` |
| Mean Well -V (PSU) | PLC `C` (D2-08ND3 input common) | Blue/W stripe (or White) | `0V-COM` |

### VFD Digital Control (PLC outputs → VFD inputs)

The PLC's D2-08TR relay output module drives the VFD's control inputs in sinking mode. The relay module's common (`C` terminal) is wired to PSU `-V`, so each Y output sinks to 0V when its relay closes.

| From | To | Wire label | Function |
|---|---|---|---|
| PLC Y7 (D2-08TR) | VFD `FOR` | `FOR` | Forward run command |
| PLC Y6 (D2-08TR) | VFD `REV` | `REV` | Reverse run command |
| PLC Y5 (D2-08TR) | VFD `RST` | `RST` | Fault reset pulse |
| PSU -V | D2-08TR relay common AND VFD `DCM` | `0V-CTRL` | Shared 0V reference for sinking inputs |

When a Y output is energized, its relay closes and pulls the corresponding VFD input to DCM (0V), activating the input via the VFD's internal pull-up to its own +24V rail.

## Required VFD Parameter Settings

These must be programmed via the VFD keypad. Power-cycle the VFD after changing values if they don't appear to take effect immediately.

| Code | Value | Meaning |
|---|---|---|
| `PD052` | `02` | FA-FB-FC relay function = Fault Indication (relay closes on any VFD fault). Note: `12` (Over-torque Detect) was tested and does not actuate the relay on this firmware revision when `PD123 = 2`. |
| `PD123` | `3` | Over-torque detect mode = detect during running, stop on detect. This triggers a `dT` fault when over-torque is detected, which fires the fault relay configured by `PD052 = 02`. |
| `PD124` | `150` | Over-torque level = 150% of motor rated current. Production motor (IronHorse, `PD142 = 5.93 A`) → **8.9 A** trip. Currently-programmed bench values (`PD142 = 7.6 A`) → 11.4 A trip. Tune lower if real jams are missed, higher if hard cuts cause nuisance trips. |
| `PD125` | `3.0` | Over-torque detect time = 3.0 seconds. Motor must draw current above `PD124` threshold continuously for 3.0 seconds before the VFD trips. |
| `PD155` | `0` | Auto-restart attempts = 0 (disabled). The PLC handles all restart logic to maintain the 3-strike lockout. Do not enable VFD auto-restart for safety reasons (NFPA 79 §7.5). |

Motor parameters (`PD141`–`PD144`) must also be programmed per the motor nameplate. See [`VFD/Motor_Nameplate.md`](../VFD/Motor_Nameplate.md).

To program: press `PRGM` to enter programming mode, navigate with arrows, press `SET` to edit, change value, press `SET` to save. Press `PRGM` twice to exit.

## Guaranteed Trip Verification

First-pass test to confirm the VFD trip mechanism and the relay-to-PLC signal chain work end-to-end. The aggressive threshold guarantees the VFD will trip on any motor activity.

### Test parameter values

| Code | Production value | Guaranteed-trip test value |
|---|---|---|
| `PD052` | `02` | `02` (no change) |
| `PD123` | `3` | `3` (no change) |
| `PD124` | `150` | `5` (5% × `PD142` — about 0.30 A on the IronHorse FLA, 0.38 A on the GE bench value — trips on any motor activity) |
| `PD125` | `3.0` | `5.0` (5-second window) |

### Procedure

1. Decouple motor from any mechanical load (shaft must spin freely).
2. Program the test values and confirm each on the keypad.
3. Power up the PLC.
4. Verify idle state: with motor stopped, X5 LED should be OFF on the D2-08ND3. If it is ON at idle, the wiring is wrong (e.g., wires on FB instead of FA, or short circuit).
5. Command motor to run forward at 10–15 Hz.
6. Within ~5 seconds the VFD should trip with `dT` fault. At trip:
   - Motor stops
   - VFD display shows fault code
   - Fault relay fires → X5 LED comes ON on the D2-08ND3
7. Verify the PLC ladder logic reacts (drops Y7, starts unjam routine).
8. Press the VFD STOP button (or pulse Y5/RST) to clear the fault.
9. After fault clears, X5 LED should turn OFF again.

### What it proves

- VFD over-torque detection works
- `dT` fault triggers fault relay (PD052 = 02 functions correctly)
- FA-FC contact closes when fault occurs
- +24V reaches X5 through the wiring
- PLC reads X5 correctly
- Ladder logic responds to the rising edge of X5

### Failure-mode troubleshooting

| Symptom | Likely cause |
|---|---|
| X5 LED ON at idle (before test starts) | Wires on FB instead of FA (NC instead of NO), or short circuit between FA and FC |
| Motor runs forever, no trip | `PD124` not actually saved at low value, or VFD in latched fault state — check `PD180` for last fault |
| Motor stops with fault code but X5 LED stays OFF | Wire break between FC and PLC X5, fuse blown, or PSU -V not connected to PLC C terminal |
| Motor stops but display shows fault other than `dT` (e.g., `OC-1`, `OC-2`) | Hardware overcurrent triggered before over-torque firmware timer — raise `PD124` to a less aggressive value |

### Restoration after testing

| Code | Restore to |
|---|---|
| `PD124` | `150` |
| `PD125` | `3.0` |

(`PD052` and `PD123` were not changed during testing.)

## Behavior Summary

| State / Event | What Happens | What PLC Sees |
|---|---|---|
| VFD off or PLC just powered on | No +24V flowing through relay | X5 = LOW |
| Normal operation, no jam | Relay idle, FA-FC open | X5 = LOW → "system healthy" |
| Motor current rises above `PD124 × PD142` (8.9 A on the IronHorse FLA, 11.4 A on the GE bench value) | VFD starts over-torque timer (3.0 s window) | X5 still LOW |
| Sustained over-current reaches 3.0 s | VFD self-trips with `dT` fault → motor stops → fault relay fires → FA-FC closes (+24V from FA flows through to FC) | X5 = HIGH → rising edge → jam counter +1 → unjam routine begins |
| PLC unjam routine | Drops Y7 (FOR), pulses Y5 (RST, 500 ms), waits, pulses Y6 (REV, 2 s), pulses Y5 again, re-engages Y7 | Y5/Y6/Y7 cycle through the recovery sequence |
| Each new over-current event | New `dT` trip, new fault relay fire | New rising edge of X5, jam counter increments |
| 3 jam events within one session | PLC latches `LOCKOUT` | Motor stops permanently, fault lamp on, operator controls disabled until manual reset |
| Deadman released >30 s continuously | Session reset timer fires | Jam counter resets to 0 |
| Motor runs cleanly for >30 s after a jam | Clean-run reset timer fires | Jam counter resets to 0 |
| Operator presses Reset button | LOCKOUT clears | Jam counter resets, normal operation resumes |
| Brake resistor missing/undersized during reversal | VFD may trip on `Ou-1` / `Ou-2` overvoltage | X5 = HIGH (fault relay fires on any fault) → PLC treats as jam |

## Related Documentation

- [Motor nameplate](../VFD/Motor_Nameplate.md) — motor specs and required VFD motor parameters
- [Brake resistor wiring](Brake_Resistor_Wiring.md) — P/Pr terminal wiring for regenerative braking
- [VFD parameter codes](VFD_PD_Codes.pdf) — full HY-series parameter manual
- [Wire color standard](../electrical/Wire_Color_Standard.md) — panel-wide NFPA 79 color conventions

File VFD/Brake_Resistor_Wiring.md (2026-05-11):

# Brake Resistor Wiring

This document describes how the dynamic braking resistor is wired to the Huanyang HY-series VFD and how it is sized for the shredder application.

## Why a Brake Resistor is Needed

When the VFD decelerates the motor (commanded stop, reversal, or normal slowdown), the motor acts briefly as a generator. The kinetic energy stored in the rotating mass of the motor, shaft, gearbox, and shredder blades flows back into the VFD as electrical energy. This energy charges the VFD's DC bus capacitors, raising the bus voltage above its normal level.

If nothing dissipates this regenerative energy, the bus voltage keeps climbing until the VFD trips on an **overvoltage fault (`Ou-1` / `Ou-2`)** to protect itself. The motor then coasts to a stop instead of decelerating under control, which defeats the purpose of the commanded stop.

A brake resistor solves this. The VFD contains an internal brake transistor (chopper) that switches the resistor across the DC bus whenever the bus voltage rises above the braking threshold. The regenerative energy flows into the resistor and is dissipated as heat. The bus voltage stays in range and the deceleration proceeds normally.

### Why this matters for the shredder

The shredder application generates regenerative energy in three situations:

1. **Normal stop (operator releases deadman)** — the motor decelerates the inertia of the shaft and blades.
2. **Auto-clear forward/reverse cycling during jam recovery** — each direction reversal first decelerates the motor to zero, then accelerates in the opposite direction. The deceleration half of each cycle dumps regenerative energy.
3. **E-stop trip** — fastest possible deceleration, largest regenerative pulse.

Without a brake resistor, frequent forward/reverse cycling (jam recovery) will reliably trip the VFD on overvoltage every time, breaking the auto-clear feature. The brake resistor is not optional for this application.

## VFD Terminals (P and Pr)

The brake resistor connects to two terminals on the VFD's **main circuit (power) terminal block** — not the control terminal block where the FA/FB/FC and FOR/REV terminals live. The brake resistor terminals are on the same row as the main AC input (R/S/T) and motor output (U/V/W) terminals.

| Terminal | Function |
|---|---|
| **P** | Positive DC bus terminal — one end of the brake resistor |
| **Pr** | Brake chopper output — other end of the brake resistor |

The terminal label on the VFD is typically printed as `P.Pr` indicating these two terminals work as a pair.

Some larger VFDs also have separate `P` and `N` terminals for connecting an *external* braking unit (a standalone chopper + resistor module used when the internal chopper cannot handle the regenerative power). For the 3 HP shredder, the VFD's internal chopper is sufficient and the resistor connects directly to **P and Pr**.

## Resistor Sizing

Two specifications matter: **resistance (ohms)** and **power dissipation (watts)**.

### Resistance value

The resistance value sets the peak current the brake transistor must handle. **Too low** = excessive current = brake transistor damage (`bt` fault). **Too high** = poor braking performance.

For the HY-series 220V class VFD driving a 3 HP / 2.2 kW motor:

| Motor / VFD class | Typical brake resistor resistance |
|---|---|
| 1-2 HP, 220V class | 100-200 Ω |
| **3 HP, 220V class** | **50-100 Ω (recommended: 75 Ω)** |
| 5 HP, 220V class | 30-50 Ω |
| 7.5 HP, 220V class | 25-40 Ω |

Confirm the minimum allowable resistance with the VFD's specific datasheet before ordering. Going below the minimum will damage the internal brake transistor.

### Power rating (watts)

The power rating sets how much continuous heat the resistor can dissipate without overheating. Higher = more headroom for frequent braking.

Sizing depends on braking duty cycle:

| Braking duty | Wattage for 3 HP shredder |
|---|---|
| Occasional stops only (no reversing) | 300 W |
| **Frequent stops, occasional reversals** | **500 W (recommended starting point)** |
| Heavy reversing duty (jam-clear cycles every minute) | 750-1000 W |

For the shredder, the auto-clear feature triples the braking duty during jam events. A **500 W resistor** is the recommended starting point — it provides headroom for typical use and the auto-clear routine, but is not so oversized that cost becomes excessive.

If lockouts from frequent `Ou` (overvoltage) faults appear during jam-clear cycles, upgrade to a 750 W or 1000 W resistor.

### Recommended part

| Spec | Value |
|---|---|
| Resistance | 75 Ω |
| Power rating | 500 W |
| Form factor | Aluminum-clad chassis-mount or open wire-wound |
| Voltage rating | ≥ 400 VDC |

Common sources: Vishay, Ohmite, Mouser/Digikey generic. Search "75 ohm 500W braking resistor VFD."

## Wiring Table

The brake resistor has only two terminals and no polarity — either end can connect to P or Pr.

| From | To | Wire color | Wire label |
|---|---|---|---|
| VFD `P` terminal (main power terminal block) | Brake resistor terminal 1 | Black | `BR-P` |
| VFD `Pr` terminal (main power terminal block) | Brake resistor terminal 2 | Black | `BR-Pr` |

**Wire gauge: 14 AWG stranded minimum** (12 AWG preferred). The brake resistor handles brief pulses of high current — a few amps continuous but tens of amps peak during heavy braking. Undersized wire heats up and adds resistance in series with the resistor, reducing braking effectiveness.

**Wire color:** NFPA 79 §13.2 specifies **Black for power-class wiring at line voltage**, which is the correct class for the DC bus connection at P and Pr (DC bus voltage on a 220V VFD runs ~300-400 VDC during braking).

**Wire length: as short as possible** — ideally under 1 meter (3 feet) between VFD and resistor. Long brake resistor wires add inductance, which causes voltage spikes that can damage the brake transistor. If the resistor must be mounted further from the VFD, use twisted-pair routing to cancel inductance.

## Physical Mounting

The brake resistor gets **hot** — easily 200-400°C surface temperature during heavy braking. Mounting requirements:

1. **Mount outside the VFD enclosure** if possible, or in a dedicated vented section away from electronics. The heat will cook nearby components if confined.
2. **Provide free airflow** around the resistor on all sides. Aluminum-clad resistors are typically rated assuming free convection — boxing them in derates the wattage by 50% or more.
3. **Keep flammable materials at least 6 inches away** — wire insulation, plastic conduit, paper labels, anything combustible.
4. **Use heat-rated wire near the resistor** — the last 12 inches of brake wire should be silicone-insulated or fiberglass-sleeved if the resistor is open-frame.
5. **Mechanically isolate from sensitive components** — vibration and thermal expansion can loosen terminals over time.
6. **Label clearly** — "HOT SURFACE" placard near the resistor warns maintenance staff. NFPA 79 requires hazard labeling for components above 60°C surface temperature.

## Required VFD Parameter Settings

The HY series enables dynamic braking automatically when a resistor is connected — no parameter changes are strictly required. However, two related parameters can be tuned:

| Code | Default | Description |
|---|---|---|
| `PD118` | `1` | Over-voltage stall prevention. `1` = enabled. Keep enabled — this is a backup that delays deceleration if the bus voltage rises despite the brake resistor (e.g., resistor disconnected or too small). |
| `PD031` | `2.0` | DC braking voltage level at start/stop. This is for the *DC injection braking* function (zero-frequency holding), separate from the dynamic braking that uses the resistor. Leave at default for shredder. |

The brake transistor switches automatically when DC bus voltage exceeds the internal braking threshold (factory-set, not user-adjustable on most HY revisions). The user does not need to configure when to brake — only ensure the resistor is connected and correctly sized.

## Optional: Brake Resistor Monitoring

The VFD's multi-function outputs include function code `32: Braking Resistor Act` — when assigned, the corresponding output closes whenever the brake transistor is firing. This can be wired to a PLC input or panel lamp for monitoring brake activity, useful for verifying the resistor is working and for diagnosing why deceleration is or is not happening as expected.

For example, assigning `PD053 = 32` would activate the KA-KB relay (if present on this VFD revision) every time the brake fires. Not required for normal operation — only useful for diagnostics or research.

## Behavior Summary

| Event | Internal Action | Result |
|---|---|---|
| Motor commanded to decelerate (stop, reverse, slowdown) | Motor acts as generator, regenerates energy into DC bus | Bus voltage rises |
| Bus voltage exceeds internal braking threshold | Brake transistor switches the resistor across the DC bus | Regenerative energy dissipated as heat in resistor |
| Bus voltage drops back below threshold | Brake transistor turns off | Deceleration continues |
| Deceleration ramp ongoing | Brake transistor cycles rapidly (PWM-style) | Bus voltage stays in range until motor reaches commanded speed |
| Brake resistor missing or undersized | Bus voltage rises uncontrolled | VFD trips on `Ou-1` / `Ou-2` (overvoltage); motor coasts instead of decelerating |
| Brake resistor wire shorted, or resistance too low | Brake transistor draws excessive current | VFD trips on `bt` (braking transistor damage); permanent damage possible |

## Safety Notes

- The brake resistor terminals (P and Pr) sit on the **DC bus at ~300-400 VDC during operation and for up to 5 minutes after power-off** (until bus capacitors discharge). Always wait for the VFD's POWER LED to fully extinguish before touching these terminals.
- The resistor itself can reach **200-400°C surface temperature**. Allow 15+ minutes cool-down before any maintenance.
- Brake resistor mounting location should be **inaccessible to operators during normal operation** — behind guards, inside the panel, or shielded.
- Never run the shredder without a brake resistor connected if the auto-clear routine is enabled. The repeated forward/reverse cycling will trip the VFD on overvoltage every time, breaking the feature.

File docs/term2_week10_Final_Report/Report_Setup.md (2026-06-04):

# Final Report — Setup & Build Guide

> **Starting fresh or duplicating this layout on another project?**
> Read [`REPORT_TEMPLATE_GUIDE.md`](REPORT_TEMPLATE_GUIDE.md) first — it has the
> reusable preamble, title page, table styles, ladder-logic / HMI section
> patterns, and pitfalls list. This file is the **project-specific** build
> notes for the Universal Plastic Shredder report.

How to build, edit, and regenerate the EE capstone final report
(`src/Final_Report.tex`). The report is a single LaTeX document styled
after the PSU MCECS / Power Engineering Lab report template (green section
headings, blue subsections, HRule title page with the MCECS logo, `fancyhdr`
header/footer).

---

## 1. Files

| File | Purpose |
|---|---|
| `Final_Report.tex` | The report source (everything except the point-list appendix). |
| `appendix_pointlist.tex` | **Auto-generated** Appendix B (the full PLC point list). Do **not** edit by hand — regenerate it (see §4). |
| `gen_pointlist.py` | Generator that turns `PLC/Point_List.xlsx` into `appendix_pointlist.tex`. |
| `images/psuMCECSloghoriz.png` | MCECS horizontal logo used on the title page. |
| `images/image.png` | Operator control-panel drawing (Figure 1). |
| `Final_Report.pdf` | The built output (commit it so reviewers don't need a TeX install). |

The report also reads `../PLC/Point_List.xlsx` indirectly (through the
generator) and `../PLC/Point_List.pdf` is the standalone rendered workbook.

---

## 2. Toolchain

You need a LaTeX distribution with `pdflatex` plus the packages below, and
Python 3 with `openpyxl` for the point-list generator.

**Debian/Ubuntu:**
```bash
sudo apt-get update
sudo apt-get install -y --no-install-recommends \
  texlive-latex-base texlive-latex-recommended texlive-latex-extra texlive-fonts-recommended
pip install openpyxl
```

**macOS:** install MacTeX (or BasicTeX + `tlmgr install` the packages below), then `pip install openpyxl`.

### LaTeX packages used
`geometry, graphicx, float, caption, setspace, fancyhdr, enumitem, hyperref,
xcolor, titlesec, colortbl, booktabs, parskip, tabularx, xltabular, tikz,
pdfpages, pdflscape`. All ship with a full TeX Live (`texlive-latex-extra`
covers `xltabular`, `pdflscape`, `pdfpages`).

---

## 3. Build

From `docs/term2_week10_Final_Report/src/`:

```bash
pdflatex -interaction=nonstopmode Final_Report.tex
pdflatex -interaction=nonstopmode Final_Report.tex   # 2nd pass: TOC + table refs
```

Run **twice** so the table of contents and the `Table~\ref{...}` cross-references
resolve. A third pass never hurts. Then clean the aux files:

```bash
rm -f Final_Report.{aux,out,toc,log,lof,lot}
```

The current report is ~48 pages (the point-list appendix is the bulk of it).

---

## 4. Regenerating the point-list appendix (Appendix B)

Appendix B is transcribed from the Excel workbook so it matches the as-built
wiring exactly. **Whenever `PLC/Point_List.xlsx` changes, regenerate it:**

```bash
# from the repo root
python3 docs/term2_week10_Final_Report/src/gen_pointlist.py "PLC/Point_List.xlsx" docs/term2_week10_Final_Report/src/appendix_pointlist.tex
# then rebuild the PDF (§3)
```

The generator emits one landscape, full-grid table per workbook sheet using the
spreadsheet columns: *Point Description · Origin Address · DO · DI · AO · AI ·
Pwr · Destination Address · Destination Description · Notes*. It handles both the
10- and 11-column sheet layouts and escapes special characters for LaTeX.

> The report also keeps a standalone rendered copy of the workbook at
> `PLC/Point_List.pdf`. That one is exported from Excel/LibreOffice, not from
> this script.

---

## 5. Document structure & style

- **Title page** — `titlepage` with `\HRule` rules, the MCECS logo, team /
  sponsor / advisors, and the course line. Labeled "Final Report — Rough Draft".
- **Section colors** — `\titleformat` makes sections PSU green and subsections
  PSU blue. Colors are defined near the top: `PSUgreen` (106,127,16), `PSUblue`
  (0,117,154), `PSUgray` (71,67,52).
- **Header/footer** — `fancyhdr`: running title + course in the header, project
  line + page number in the footer (PSU gray).
- **Draft markers** — three helper macros flag unfinished content:
  - `\todo{...}` → red **[TODO: ...]**
  - `\note{...}` → blue *[NOTE: ...]*
  - `\question{...}` → magenta **[QUESTION: ...]**
  Search the source for `\todo`, `\note`, `\question` to find everything still
  open before the final submission.
- **Tables** — all tables are full grids (`|...|` column specs + `\hline` on
  every row). Wide reference tables use `xltabular` so they break across pages
  with a repeated header.

### Common edits
- **Team / sponsor / advisors:** the title-page `minipage` (each name is wrapped
  in `\mbox{}` so it never splits across a line).
- **Logo / panel figure:** swap the files in `images/`.
- **Final motor:** the production motor is the **IronHorse MTCP2-002** (2 HP,
  230 V, 5.93 A FLA, 4-pole, 1735 RPM, VFD-rated 1.0 SF). The submitted Final
  Report still cites the **GE 5KE182BC205B** bench/test motor for traceability
  with the weekly progress reports; the as-built nameplate values live in
  [`VFD/Motor_Nameplate.md`](../../VFD/Motor_Nameplate.md). If you re-spin the
  Final Report after a re-program, swap §5.2 `PD141`/`PD142`/`PD144` and the
  NEC 430 references to the IronHorse FLA and re-verify the sizing.
- **VFD parameters:** the table in §5.2 (`\label{tab:vfdparams}`) is the single
  source — Appendix D references it.

---

## 6. Quick checklist before the final

- [ ] Regenerate Appendix B if the point list changed (§4).
- [ ] Resolve all `\todo` / `\question` markers.
- [ ] Resolve the NFPA 79 neutral-switching deviation (or document the
      justification).
- [ ] Confirm whether a formal ISO 13849-1 PL verification is in scope (the
      report carries a *preliminary* assessment only).
- [ ] Insert the wiring diagrams in Appendix C and a system block diagram in
      System Architecture.
- [ ] Rebuild the PDF (twice) and commit `Final_Report.pdf`.

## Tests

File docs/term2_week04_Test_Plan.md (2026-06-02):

# Test Plan v1.0 — Universal Plastic Shredder V2.0 Electrical System

**Course:** ECE 412 Senior Project Development, Portland State University  
**Sponsor:** MME / Ichor Systems (Bridget Lannigan)  
**Team:** Bao Nguyen, Fearghus Tyler, Yaqoub Rabiah, Fox Kang  
**Date of Test:** ___________  
**Tester:** ___________

---

## Purpose

To verify the electrical control system of the Universal Plastic Shredder V2.0 against its requirements, using both top-down (full-system operational) and bottom-up (subsystem-by-subsystem) test methods.

---

## Equipment Needed

### System Equipment
- Shredder electrical enclosure (PLC, VFD, contactor, fuse blocks, PSU, wiring complete)
- EA1-T4CL C-More Micro-Graphic HMI touch panel (mounted, cabled)
- 3–5 HP motor + gearbox (ME interface, mechanically coupled)
- E-stop button, two-hand start buttons (Fwd, Deadman SW1/SW2), lid interlock switch
- Status indicator lights (Power / Running / Fault)
- AC power cord/supply (120 VAC or 208–240 VAC, as applicable)

### Test Equipment
- Digital multimeter (voltage, continuity, current clamp)
- Tachometer or optical RPM sensor (to verify shaft speed)
- Clamp-on ammeter (motor current)
- Laptop with DirectSOFT5 (PLC programming software) and USB-to-serial adapter
- C-More programming cable + EA-MG-PGM-CBL software cable (for HMI)
- Sample plastic pieces: PVC, PP, or LDPE sheet, 0.25–0.5" thick, 4–12" wide

### Other Equipment
- Personal protective equipment: safety glasses, hearing protection
- Fire extinguisher (Class C, electrical)
- Second person present for all powered tests (safety requirement for industrial equipment)

---

## Pre-Test Setup

1. Confirm the area around the shredder is clear of loose material.
2. Confirm the lid interlock switch is functional: manually actuate it and verify the NC contact opens/closes with a multimeter before powering on.
3. Set the AC power supply to match the system's rated input voltage. Verify with a multimeter before connecting.
4. Confirm all wiring terminations are secure (no loose lugs, no exposed conductors).
5. Confirm fuses are seated: 25A (PSU branch), 1A (PLC branch), 1.5A (pushbutton commons), 1/2A slow-blow (contactor coil fuse DF103V).
6. Connect DirectSOFT5 laptop to the H2-DM1E CPU via Ethernet or serial — confirm communication before starting tests.
7. Confirm the VFD (HY02D211B-T) is powered off and the contactor (SD-N35) is open before initial power-on.
8. Place test plastic material near the input chute but do not feed until instructed.

---

## Part 1: Top-Down Test

*Tests M1, M2, M4, M6, M7, M9, S1, S3*

### Top-Down Test Steps

**Phase 1 — Power On**

1. Switch on main AC disconnect / power switch.
   - **Power indicator light** (status light) should illuminate. ☐  *Tests: S1 (power indicator)*
   - Measure 24VDC at PSU output terminals. Should be 24 ± 2 VDC. Reading: _______ V  
   - PLC CPU (H2-DM1E) should boot — RUN LED on CPU should go green within ~5 seconds. ☐

2. Observe HMI display (EA1-T4CL).
   - Display should power on and show **"IDLE / READY"** state screen. ☐  *Tests: M9 (HMI powers on)*
   - Confirm system state shown on HMI reads: **Idle** ☐  *Tests: M9 (state display)*

**Phase 2 — Safety Pre-check (lid open, no start)**

3. Confirm lid interlock is triggered (lid open or switch manually held open).
   - Attempt to press Forward button.
   - Motor must NOT start. ☐  *Tests: M6 (lid interlock prevents run)*
   - HMI should display fault or interlock message. ☐

4. Close lid (or release interlock switch). HMI should return to Ready/Idle state. ☐

**Phase 3 — Normal Start Sequence**

5. With lid closed, press and hold both Deadman SW1 and SW2 simultaneously, then press Forward.
   - Contactor (SD-N35) should close (audible click). ☐
   - Motor should begin spinning. ☐
   - **Running indicator light** should illuminate. ☐  *Tests: S1 (running indicator)*
   - HMI should display **"Running"** state and current motor speed (RPM or Hz). ☐  *Tests: M9 (running state display)*

6. Allow motor to reach steady-state speed (~5 seconds). Measure output shaft RPM with tachometer.
   - Reading: _______ RPM. Should be 70–90 RPM. ☐  *Tests: M7 (speed in range)*
   - If speed is outside range, note VFD frequency command and adjust as needed.

**Phase 4 — Shred Test**

7. With motor running at target speed, hand-feed one plastic test piece (0.25–0.5" thick, 4–12" wide) into the input chute.
   - Shredder should accept and process the piece without stalling or faulting. ☐
   - Collect output — pieces should be approximately 1" in size. ☐  *Tests: M1 (shreds to ~1")*
   - Motor should return to target RPM after piece clears. ☐

**Phase 5 — Normal Stop**

8. Release one or both Deadman buttons (or press Stop if available on HMI).
   - Motor should stop (contactor opens). ☐
   - Running light should extinguish. ☐
   - HMI should return to **"Idle"** state. ☐

**Phase 6 — Emergency Stop**

9. Restart motor per Step 5. Confirm motor is running.
10. Press E-stop button.
    - Motor must stop immediately (contactor drops out). ☐  *Tests: M4 (E-stop shuts down)*
    - Running light should extinguish. ☐
    - HMI should display **"Fault / E-stop"** state. ☐  *Tests: M9 (fault state display)*
    - **Fault indicator light** should illuminate. ☐  *Tests: S1 (fault indicator)*

11. Twist/release E-stop button to reset.
    - Confirm system returns to Idle (motor does not auto-restart). ☐  *Tests: M4 (no auto-restart after E-stop)*

**Phase 7 — Power Off**

12. Switch off main AC disconnect.
    - All lights should extinguish. HMI should power off. Motor (if running) should stop. ☐

### Top-Down Test Conclusions

| Requirement | Result | Notes |
|---|---|---|
| M1 — Shreds to ~1" | ☐ Pass ☐ Fail | |
| M2 — VFD used and controllable | ☐ Pass ☐ Fail | |
| M4 — E-stop shuts down safely | ☐ Pass ☐ Fail | |
| M6 — Lid interlock prevents run | ☐ Pass ☐ Fail | |
| M7 — 70–90 RPM shaft speed | ☐ Pass ☐ Fail | Measured: _____ RPM |
| M9 — HMI shows state and control | ☐ Pass ☐ Fail | |
| S1 — Status/fault lights work | ☐ Pass ☐ Fail | |
| S3 — Controls clearly labeled | ☐ Pass ☐ Fail | |

---

## Part 2: Bottom-Up Test

---

### Test Case BU-01: AC Power Input and Fuse Block

| | |
|---|---|
| **Test ID** | BU-01 |
| **Test Case Name** | AC Power Input and Fuse Distribution |
| **Description** | Verify AC power reaches the fuse block and distributes correctly to the PSU and PLC branches. |
| **Type** | Black box |
| **Tester** | |
| **Date** | |
| **HW/SW Version** | 1.0 |
| **Setup** | Main disconnect OFF. Multimeter set to AC voltage. |

| # | Input | Expected Output | Pass | Fail | N/A | Comments |
|---|---|---|---|---|---|---|
| 1 | Main disconnect ON | AC line voltage present at EURO S10H-5H fuse block input (measure L and N terminals) | ☐ | ☐ | ☐ | Reading: _____ VAC |
| 2 | Main disconnect ON | 25A fuse branch: AC present at PSU input terminals | ☐ | ☐ | ☐ | |
| 3 | Main disconnect ON | 1A fuse branch: AC present at PLC L terminal | ☐ | ☐ | ☐ | |
| 4 | Pull 25A fuse (disconnect first) | AC removed from PSU branch; PLC branch unaffected | ☐ | ☐ | ☐ | |
| 5 | Reinstate 25A fuse | Normal distribution restored | ☐ | ☐ | ☐ | |

**Overall BU-01 Result:** ☐ Pass ☐ Fail

---

### Test Case BU-02: 24VDC Power Supply

| | |
|---|---|
| **Test ID** | BU-02 |
| **Test Case Name** | 24VDC PSU Output (Mean Well NDR-480-24) |
| **Description** | Verify the PSU outputs correct 24VDC to PLC I/O, contactor coil, and pushbutton commons. |
| **Type** | Black box |
| **Tester** | |
| **Date** | |
| **HW/SW Version** | 1.0 |
| **Setup** | AC power ON. Multimeter set to DC voltage. |

| # | Input | Expected Output | Pass | Fail | N/A | Comments |
|---|---|---|---|---|---|---|
| 1 | AC applied to PSU | +V terminal: 24 ± 2 VDC at PSU output | ☐ | ☐ | ☐ | Reading: _____ VDC |
| 2 | AC applied to PSU | –V terminal: 0V (return) | ☐ | ☐ | ☐ | |
| 3 | AC applied | 1.5A fused pushbutton commons: 24VDC at each common (Fwd, Rev, DM1, DM2) | ☐ | ☐ | ☐ | |
| 4 | AC applied | Contactor coil A2 terminal: 0VDC (contactor open at rest) | ☐ | ☐ | ☐ | |

**Overall BU-02 Result:** ☐ Pass ☐ Fail

---

### Test Case BU-03: PLC Boot and Communication

| | |
|---|---|
| **Test ID** | BU-03 |
| **Test Case Name** | PLC Rack Initialization (DirectLOGIC 205) |
| **Description** | Verify the PLC CPU boots, all modules are recognized, and DirectSOFT5 can read I/O status. |
| **Type** | White box |
| **Tester** | |
| **Date** | |
| **HW/SW Version** | 1.0 |
| **Setup** | AC power ON. DirectSOFT5 open on laptop and connected to H2-DM1E via Ethernet. |

| # | Input | Expected Output | Pass | Fail | N/A | Comments |
|---|---|---|---|---|---|---|
| 1 | Power on PLC | CPU RUN LED: solid green within 10 seconds | ☐ | ☐ | ☐ | |
| 2 | DirectSOFT5 connect | PLC goes online; no I/O errors reported | ☐ | ☐ | ☐ | |
| 3 | DirectSOFT5 data view | All discrete inputs X0–X7 readable (0 or 1) | ☐ | ☐ | ☐ | |
| 4 | DirectSOFT5 data view | All discrete outputs Y0–Y7 readable (0 at startup) | ☐ | ☐ | ☐ | |
| 5 | DirectSOFT5 data view | Analog input F2-06AD-1 registers readable | ☐ | ☐ | ☐ | |
| 6 | DirectSOFT5 data view | RTD input F2-04RTD registers readable; ambient temp reasonable (15–30 °C) | ☐ | ☐ | ☐ | Reading: _____ °C |
| 7 | Ladder logic running | No ladder logic errors or fault codes in CPU status | ☐ | ☐ | ☐ | |

**Overall BU-03 Result:** ☐ Pass ☐ Fail

---

### Test Case BU-04: Emergency Stop Circuit

| | |
|---|---|
| **Test ID** | BU-04 |
| **Test Case Name** | E-Stop Hardware Safety Circuit |
| **Description** | Verify the E-stop button breaks the safety circuit and drops all motor-related outputs. Tests M4. |
| **Type** | Black box |
| **Tester** | |
| **Date** | |
| **HW/SW Version** | 1.0 |
| **Setup** | AC power ON, PLC running ladder logic. Motor is NOT running. Multimeter on safety circuit nodes. |

| # | Input | Expected Output | Pass | Fail | N/A | Comments |
|---|---|---|---|---|---|---|
| 1 | E-stop released (normal) | Safety circuit continuity: confirmed (multimeter, or circuit logic per Deadman_Logic_v2.pdf) | ☐ | ☐ | ☐ | |
| 2 | Press E-stop | Safety circuit opens immediately | ☐ | ☐ | ☐ | |
| 3 | Press E-stop while motor running (from BU-07 run) | Contactor (SD-N35) drops out within 1 second | ☐ | ☐ | ☐ | |
| 4 | Press E-stop | Y0 (contactor coil output) = 0 in DirectSOFT5 | ☐ | ☐ | ☐ | |
| 5 | Release E-stop (twist/pull) | System does NOT auto-restart motor | ☐ | ☐ | ☐ | |
| 6 | Release E-stop, then re-initiate two-hand start | Motor can restart normally after E-stop reset | ☐ | ☐ | ☐ | |

**Overall BU-04 Result:** ☐ Pass ☐ Fail

---

### Test Case BU-05: Two-Hand Start / Deadman Circuit

| | |
|---|---|
| **Test ID** | BU-05 |
| **Test Case Name** | Two-Hand Start (Deadman) Safety Logic |
| **Description** | Verify the motor only runs when both deadman buttons are held simultaneously with Forward. Tests M6. |
| **Type** | Black box |
| **Tester** | |
| **Date** | |
| **HW/SW Version** | 1.0 |
| **Setup** | AC power ON, PLC running, E-stop released, lid closed. Per Deadman_Logic_v2.pdf. |

| # | Input | Expected Output | Pass | Fail | N/A | Comments |
|---|---|---|---|---|---|---|
| 1 | Press Forward only (no deadman) | Motor does NOT start | ☐ | ☐ | ☐ | |
| 2 | Press SW1 only (no Forward) | Motor does NOT start | ☐ | ☐ | ☐ | |
| 3 | Press SW2 only (no Forward) | Motor does NOT start | ☐ | ☐ | ☐ | |
| 4 | Press SW1 + SW2 (no Forward) | Motor does NOT start | ☐ | ☐ | ☐ | |
| 5 | Press Forward + SW1 only | Motor does NOT start | ☐ | ☐ | ☐ | |
| 6 | Press Forward + SW2 only | Motor does NOT start | ☐ | ☐ | ☐ | |
| 7 | Press Forward + SW1 + SW2 simultaneously | Contactor closes, motor starts | ☐ | ☐ | ☐ | |
| 8 | While running: release SW1 | Motor stops immediately | ☐ | ☐ | ☐ | |
| 9 | While running: release SW2 | Motor stops immediately | ☐ | ☐ | ☐ | |

**Overall BU-05 Result:** ☐ Pass ☐ Fail

---

### Test Case BU-06: Lid Interlock

| | |
|---|---|
| **Test ID** | BU-06 |
| **Test Case Name** | Lid Interlock Safety Input |
| **Description** | Verify the lid interlock switch (discrete input to PLC) prevents motor from running when triggered. Tests M6. |
| **Type** | Black box |
| **Tester** | |
| **Date** | |
| **HW/SW Version** | 1.0 |
| **Setup** | AC power ON, PLC running, E-stop released. Interlock switch accessible. |

| # | Input | Expected Output | Pass | Fail | N/A | Comments |
|---|---|---|---|---|---|---|
| 1 | Lid closed (interlock normal) | PLC discrete input for interlock reads correct state in DirectSOFT5 (note address: ___) | ☐ | ☐ | ☐ | |
| 2 | Open lid (trigger interlock) | Interlock DI changes state in PLC | ☐ | ☐ | ☐ | |
| 3 | Lid open, attempt two-hand start | Motor does NOT start | ☐ | ☐ | ☐ | |
| 4 | Motor running, then open lid | Motor stops within 1 second | ☐ | ☐ | ☐ | |
| 5 | Close lid, reset, re-initiate start | Motor starts normally | ☐ | ☐ | ☐ | |

**Overall BU-06 Result:** ☐ Pass ☐ Fail

---

### Test Case BU-07: VFD Control and Motor Speed

| | |
|---|---|
| **Test ID** | BU-07 |
| **Test Case Name** | VFD Speed Command and Motor RPM (HY02D211B-T) |
| **Description** | Verify PLC analog output CH1 commands correct VFD speed and output shaft reaches 70–90 RPM. Tests M2, M7, M8. |
| **Type** | White box |
| **Tester** | |
| **Date** | |
| **HW/SW Version** | 1.0 |
| **Setup** | AC power ON, PLC running, safety circuits clear, motor mechanically coupled. Tachometer and multimeter ready. |

| # | Input | Expected Output | Pass | Fail | N/A | Comments |
|---|---|---|---|---|---|---|
| 1 | Motor stopped | Measure AO CH1 voltage at VFD terminal AL: ~0V | ☐ | ☐ | ☐ | Reading: _____ V |
| 2 | Initiate two-hand start | Contactor (SD-N35) closes (audible click, LED if present) | ☐ | ☐ | ☐ | |
| 3 | Motor running | AO CH1 voltage at VFD AL terminal: 0–10VDC, nonzero | ☐ | ☐ | ☐ | Reading: _____ V |
| 4 | Motor running at steady state | Tachometer at output shaft: 70–90 RPM | ☐ | ☐ | ☐ | Reading: _____ RPM |
| 5 | Motor running | Clamp ammeter on motor leads: within motor nameplate FLA (Full Load Amps) | ☐ | ☐ | ☐ | Reading: _____ A |
| 6 | Motor running | VFD keypad display: no fault codes (Er.xxx) | ☐ | ☐ | ☐ | |
| 7 | Normal stop (release deadman) | VFD ramps down; shaft stops within _____ seconds | ☐ | ☐ | ☐ | |

**Overall BU-07 Result:** ☐ Pass ☐ Fail

---

### Test Case BU-08: Overcurrent and Overload Protection

| | |
|---|---|
| **Test ID** | BU-08 |
| **Test Case Name** | Overcurrent / Overload Protection (M5) |
| **Description** | Verify the Phoenix Contact motor overload (TMC 83C 15A) and thermal overload (RTD32-180) respond to fault conditions. Tests M5. |
| **Type** | Black box |
| **Tester** | |
| **Date** | |
| **HW/SW Version** | 1.0 |
| **Setup** | AC power ON. Do NOT intentionally overload the motor to destruction; use the trip test button if the overload relay has one, or verify NC contact behavior with multimeter. |

| # | Input | Expected Output | Pass | Fail | N/A | Comments |
|---|---|---|---|---|---|---|
| 1 | Motor stopped | Phoenix Contact TMC 83C NC contact: closed (continuity) | ☐ | ☐ | ☐ | |
| 2 | Press trip/test button on TMC 83C (if available) | NC contact opens; motor contactor cannot close | ☐ | ☐ | ☐ | |
| 3 | Reset TMC 83C | NC contact closes; system restores | ☐ | ☐ | ☐ | |
| 4 | Motor running at rated load | Clamp ammeter: motor current ≤ rated FLA | ☐ | ☐ | ☐ | Reading: _____ A |
| 5 | RTD32-180 thermal overload (OUT3 path) | Verify NC contact (95→96) is in series with F2 contactor coil per wiring diagram | ☐ | ☐ | ☐ | |
| 6 | Simulate thermal trip (if test mode available) | OUT3 drives thermal overload trip; motor stops | ☐ | ☐ | ☐ | |

**Overall BU-08 Result:** ☐ Pass ☐ Fail

---

### Test Case BU-09: HMI Display and State Feedback

| | |
|---|---|
| **Test ID** | BU-09 |
| **Test Case Name** | HMI Operator Interface (EA1-T4CL C-More Micro-Graphic) |
| **Description** | Verify the HMI displays correct system state, speed, and faults, and that operator inputs on HMI are reflected in the system. Tests M9. |
| **Type** | Black box |
| **Tester** | |
| **Date** | |
| **HW/SW Version** | 1.0 |
| **Setup** | AC power ON, PLC running, HMI powered (via shared Mean Well NDR-480-24 24VDC supply). HMI-to-PLC serial link active. |

| # | Input | Expected Output | Pass | Fail | N/A | Comments |
|---|---|---|---|---|---|---|
| 1 | Power on | HMI shows system state: Idle or Ready | ☐ | ☐ | ☐ | |
| 2 | Motor running (via two-hand start) | HMI shows: Running state | ☐ | ☐ | ☐ | |
| 3 | Motor running | HMI displays current motor speed or VFD Hz | ☐ | ☐ | ☐ | |
| 4 | Press E-stop | HMI shows: Fault / E-stop state | ☐ | ☐ | ☐ | |
| 5 | Trigger lid interlock | HMI shows interlock fault or warning | ☐ | ☐ | ☐ | |
| 6 | Reset E-stop | HMI returns to Idle (no auto-restart) | ☐ | ☐ | ☐ | |
| 7 | HMI Stop (if implemented) | Motor stops when Stop pressed on HMI | ☐ | ☐ | ☐ | N/A if not implemented |

**Overall BU-09 Result:** ☐ Pass ☐ Fail

---

### Test Case BU-10: Status Indicator Lights

| | |
|---|---|
| **Test ID** | BU-10 |
| **Test Case Name** | Status Indicator Lights (Power / Running / Fault) |
| **Description** | Verify the three status lights illuminate in the correct system states. Tests S1. |
| **Type** | Black box |
| **Tester** | |
| **Date** | |
| **HW/SW Version** | 1.0 |
| **Setup** | AC power ON, PLC running. |

| # | System State | Power Light | Running Light | Fault Light | Pass | Fail | Comments |
|---|---|---|---|---|---|---|---|
| 1 | Power ON, Idle | ON | OFF | OFF | ☐ | ☐ | |
| 2 | Motor Running | ON | ON | OFF | ☐ | ☐ | |
| 3 | E-stop active | ON | OFF | ON | ☐ | ☐ | |
| 4 | Lid interlock fault | ON | OFF | ON | ☐ | ☐ | |
| 5 | Power OFF | OFF | OFF | OFF | ☐ | ☐ | |

**Overall BU-10 Result:** ☐ Pass ☐ Fail

---

## Requirements Coverage Summary

| Req ID | Requirement | BU Test(s) | Top-Down | Result |
|---|---|---|---|---|
| M1 | Shreds plastic to ~1" | — | Phase 4 | ☐ Pass ☐ Fail |
| M2 | Controllable VFD | BU-07 | Phase 3 | ☐ Pass ☐ Fail |
| M3 | NFPA-70 (NEC) design | BU-01, BU-02 (inspect wiring) | — | ☐ Pass ☐ Fail |
| M4 | E-stop safe shutdown | BU-04 | Phase 6 | ☐ Pass ☐ Fail |
| M5 | Overcurrent/overload protection | BU-08 | — | ☐ Pass ☐ Fail |
| M6 | Safety interlock (lid + two-hand) | BU-05, BU-06 | Phase 2 | ☐ Pass ☐ Fail |
| M7 | 70–90 RPM shaft speed | BU-07 | Phase 3 | ☐ Pass ☐ Fail |
| M8 | VFD supports 3–5 HP motor | BU-07 | — | ☐ Pass ☐ Fail |
| M9 | HMI for control and status | BU-09 | Phase 1, 3, 6 | ☐ Pass ☐ Fail |
| M10 | Total cost ≤ $3,000 | BOM review | — | ☐ Pass ☐ Fail |
| S1 | Status/fault indicator lights | BU-10 | Phase 1, 3, 6 | ☐ Pass ☐ Fail |
| S2 | NEMA enclosure practices | Visual inspection | — | ☐ Pass ☐ Fail |
| S3 | Controls clearly labeled | Visual inspection | — | ☐ Pass ☐ Fail |

---

## Post-Test Teardown

1. Press E-stop (if not already active).
2. Switch off main AC disconnect.
3. Wait 60 seconds for VFD DC bus capacitors to discharge before opening enclosure.
4. Disconnect laptop from PLC.
5. Remove any test plastic material from input chute and output collection area.
6. Cover or secure enclosure.

---

## Test Notes / Discussion

*(Record any anomalies, deviations from expected results, or items requiring follow-up here.)*

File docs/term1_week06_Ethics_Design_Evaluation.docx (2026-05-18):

# Design and Ethics Considerations

2023-06-15

Capstone Team # | Team 07 - I'm So Shredded INC
Capstone Name | Universal Plastic Shredder V2.0 - Electrical System
Team members | Bao Nguyen, Fearghus Tyler, Yaqoub Rabiah, Fox Kang

# Part 1: Design Considerations

You are asked to first consider these issues and then decide whether they are relevant to your capstone project Specifically, you are asked to decide whether your design needs to consider:

- Public health, safety, and welfare
- Global factors
- Cultural factors
- Environmental factors
- Economic factors

it may be unlikely that your design should consider all of these, but it is very unlikely (or impossible) that it should not consider any of these. So, the first stage is for your team to consider each of these factors and decide if they are relevant to your design. Next, you should give a short explanation for each, especially for those that you think are relevant. Explain why they are relevant and how your design may address it. It is OK if your capstone doesn’t address all of these issues. You might think about how the future of this project might affect these categories, if that helps.

Did you consider various factors in the design of your project/product? Choose Yes / No / Possibly, and discuss why you did / didn’t / might have.

Consider: | Yes/No/ Possibly | Why?

Public health, safety, and welfare

Yes

The shredder uses a 3 HP motor driving high-torque cutting blades, which presents serious injury risk during operation. Our design includes a two-hand deadman start (operator must press two physically separated buttons simultaneously), emergency stop, lid interlock, motor overload and thermal protection, motor contactor, and a 3-strike auto-recovery lockout that disables the machine after repeated jams. The control system follows NFPA 70 (NEC) and NEMA enclosure practices. The PLC ladder logic enforces all safety conditions before allowing motor operation, and any opened interlock immediately drops the motor through a hardwired safety chain independent of the PLC.
Global factors | Possibly | Plastic waste from semiconductor manufacturing is a worldwide issue. Our localized recycling solution could be replicated at other facilities globally. Components such as the Huanyang VFD are internationally sourced, and the control architecture (VFD plus PLC plus HMI) transfers cleanly to other voltage standards with minor reconfiguration. The shredder itself is designed to operate on standard 120 VAC mains common in North American facilities.
Cultural factors | No | The shredder is an industrial machine for use in a controlled manufacturing environment. There are no language, religious, or culturally specific design choices. The HMI uses English text and standard ISO machine-safety symbols, which are common across industrial settings worldwide.

Environmental factors

Yes

The primary purpose of the project is environmental. Ichor Systems currently sends thick plastic sheet waste (PVC, polypropylene, LDPE) to landfill. Our shredder produces approximately 1-inch pieces that can be recycled or repurposed, diverting waste from disposal. The VFD-based motor control reduces electrical inrush and improves efficiency compared to across-the-line starters. A brake resistor handles regenerative energy during deceleration cycles rather than dissipating it as nuisance overvoltage trips. The motor and VFD are sized appropriately to the load rather than oversized, which reduces idle losses.

Economic factors

Yes

Commercial industrial shredders capable of handling 0.25 to 0.5 inch rigid plastic sheets cost over $10,000, while consumer-grade shredders cannot process the thicker materials Ichor generates. Our total project budget is $3,000 (EE portion approximately $1,000), which forced careful component selection. We chose the Huanyang VFD at around $150 over the ATO at around $450 after building a decision matrix that weighted price, current capability, build quality, documentation, and reliability. Long-term, the shredder reduces Ichor's waste disposal costs and may enable the company to sell or repurpose the shredded plastic stream.

# Part 2: Ethics Considerations

In industry, you will have to recognize your own and your company’s ethical and professional responsibilities. Not only would you have to recognize them, but you would also have to make judgments regarding them. In this project, you are asked to only consider if there are any potential ethical problems that could come up in your device (product) but the quality of your explanations (i.e., your judgment) will not be evaluated. Please consider the impact of your capstone project in these contexts:

- Global
- Economic
- Environmental
- Societal

Did you consider various contexts in which ethical issues may arise in the design of your project/product? Choose if it’s applicable / not applicable / might be applicable, and why / why not / why it might be.

Consider a context for ethical decision-making | Applicable: Yes/No/Possibly | Why?
Global | Possibly | Plastic waste is a global ethical concern, so any solution that reduces it has positive global impact. Sourcing components from low-cost overseas suppliers (the Huanyang VFD from China) raises questions about labor conditions and quality control standards we cannot fully verify from the United States. We mitigated this by selecting a VFD with documented community support and clear specifications, and by building in independent PLC-based safety protections rather than relying solely on the VFD's internal logic.
Economic | Yes | The shredder reduces Ichor's waste disposal costs, which is a clear economic benefit to the sponsor. Automation of waste handling could affect employees previously responsible for managing plastic disposal, though in Ichor's case the existing waste stream goes to landfill rather than to a paid workforce. As designers, we also faced cost-versus-reliability tradeoffs on every component. We documented our decision matrix transparently so the sponsor can replace components later if a cheaper choice causes reliability issues in service.
Environmental | Yes | The positive impact (diverting plastic from landfill) is the project's core purpose. There are negative impacts worth acknowledging: the electrical energy consumed during shredding, the brake resistor dissipating regenerative energy as heat, and the eventual end-of-life disposal of the shredder itself. We sized the motor and VFD appropriately to the load rather than oversizing, which reduces continuous idle losses. The shredder enables but does not by itself complete a recycling loop, so the actual environmental benefit depends on Ichor's downstream use of the shredded material.

Societal

Yes

Worker safety is the primary societal concern. Operators interact with a high-torque cutting mechanism, so our design uses multiple redundant safety interlocks: two-hand control, emergency stop, lid interlock, motor overload, thermal shutdown, and the 3-strike auto-recovery lockout. Improper use, such as feeding metal or non-plastic materials, could damage the machine or injure operators, so the HMI provides clear status indication and the PLC enforces operating constraints. Long-term societal questions include whether automated industrial recycling reduces the demand for traditional waste-handling labor, though in Ichor's case the displaced practice is landfill disposal rather than human employment.

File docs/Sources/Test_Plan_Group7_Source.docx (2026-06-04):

# I'm So Shredded Inc. — Ichor Systems Shredder V2 Control System Test Plan

2026/05/01

# Overview

The test plan is a Standard Operating Procedure (SOP) that objectively maps your current system to its requirements (as found in your Project Description Specification (PDS)). More specifically, after running through your test plan, you should have a list of all of the requirements that your project does and doesn’t meet. The test plan can be as formal as the ECE411 table attached at the bottom of this document or as simple as a bulleted list of steps to step through. Broadly speaking, there are two kinds of testing:

# Step 1: Top Down Testing

The purpose of this test plan is to validate that the complete shredder system operates correctly and safely against its requirements. This will be done by exercising the full control chain from power-on to normal operation and shutdown.

# Step 2: Bottom Up Testing

This portion of the test plan will go over each segmented case for our full system.

Test case 1: Verify 120VAC input is correctly converted by the VFD

Test case 2: Verify the contactor energizes and de-energizes correctly under control commands

Test case 3: VFD outputs to the motor across a range of frequencies

Test case 4: Verification of safety devices( E-stop, dead man switches) independently function

Test case 5: Verify the HMI correctly sets the frequency and shows the system+telemetry information

# Caveat

We’re playing fast and loose with the word “testing” here. Technically, like in ECE411, we should be doing verification against design specification and validation against user requirements, but we don’t need to get that formal for this test plan so we can lump it all under “testing”.

# Things to remember

- Write your test plans as if someone who is NOT on your team is going to run the test. And, for special extra bonus points, actually get someone who isn’t on your team to run your tests. It will really open your eyes about what assumptions you’re making about your system.
- Don’t forget about equipment needed, setup, and teardown. Again, someone who isn’t familiar with your system should be able to run these tests.

# Top Down Test Plan v1.0

Date of Test: | May 1, 2026
Tester: | Low level ee

## Purpose

To test the entire electrical control system. Validate the function of the PLC, VFD, and HMI.

## Equipment Needed

- System Equipment
  - DirectLogic 205 PLC rack
  - EA1-T4CL HMI
  - HY02D211B-T VFD
  - 120VAC Wall Power
  - Mitsubishi SN35 Contactor
  - Estop
  - Forward and Reverse button (Seperate)
  - Deadman switch (2 total)
  - CTSI Module (Capactive touch safety Module Interface)
  - Laptop
  - Gearbox and shredder
- Test Equipment
  - Hotdog sausage
  - Multimeter
  - Crowbar for jamming
  - Testa material: 0.25” and 0.5” thick PVC or PP plastic scrap
  - RPM counter goal 70-90rpm
- Other Equipment
  - Level 5 NIJ body armor
  - Safety Glasses
  - Fire extinguisher

## Pre-Test Setup

1. Confirm shredder hopper is empty and the blade chamber is clear of all material and obstructions.
2. Engage (press) E-stop to a safe state. Confirm both deadman switches are released (open).
3. Verify all wiring connections (VFD L1/L2, U/V/W, PLC I/O terminals) are tight per wiring diagram.
4. Connect laptop to PLC via programming cable. Open DirectSoft; confirm COMM LED = solid green.
5. Multimeter: E-stop contacts = open circuit (engaged) / <1 ohm (released). Check both.
6. Don PPE (Level 5 NIJ body armor + ANSI Z87.1 safety glasses). Place the fire extinguisher within 3 ft.

## Top Down Test Steps

1. Main power initialization
  a. Release E-stop (twist-pull). Switch wall breaker ON. Confirm VFD shows 0.0 Hz, no fault codes.
  b. Confirm PLC RUN LED = green, ERR = off. Confirm HMI shows READY and setpoint = 0 Hz
2. Set HMI frequency = 30 Hz.
  a. Engage both deadman switches.
  b. Confirm contactor closes (audible click),
  c. VFD ramps to 30 Hz, RPM = 70-90.
  d. Release one deadman; confirm system stops within 3 sec.

## Post-Test Teardown

1. Press E-stop, power button. Switch wall breaker OFF. Wait >= 30 sec for VFD capacitors to discharge.
2. Disconnect power cord and PLC programming cable. Inspect blade chamber for debris or damage.
3. Return test equipment to storage. Complete and sign the Conclusions section below.

## Top-down Test Plan Conclusions / Discussion

Record pass/fail for each step above. Note any fault codes, out-of-spec readings, or deviations.

Tester signature: _______________________ Date: _________

# Bottom Up Test Plan v1.0 (Template)

Test Author: Bao Nguyen
| Test Case Name: | | VFD 120 VAC Input Conversion | | | Test ID #:
| Description: | | Verify the HY02D@11B-T VFD accpets 120 VAC input and produces a stable DC bus voltage. Motor should be disconnected , no load on VFD output | | | Type: | | | □ white box ✓ black box □ _____________

Tester Information
| Name of Tester: | | | | | Date:
| HW/SW Version: | | 1.0 | | | Time:
| Setup: | | System OFF. E-stop engaged. VFD output (U/V/W) disconnected. Multimeter set to AC 600V and DC 500V ranges. PPE worn.
T E S T | INPUTS | | | EXPECTED OUTPUTS | | P A S S | F A I L | N/A | Comments
1 | Apply 120 VAC to VFD L1/L2. Measure AC voltage at input terminals | | | 108-132 VAC at L1/L2 VFD display turns in. No fault codes. Power LED is solid
2 | Measure DC bus voltage at VFD DC+/DC- terminals. CAUTION: high voltage use DC 500V range | | | DC bus ~160-170 VDC. Stable reading <5V
3 | Allow VFD to power up for 10 seconds. Read front panel display | | | Display shows 0.0 Hz. No fault or alarm codes
4 | Remove 120VAC, measure DC bus every 10 seconds until. Record de-energize time. | | | DC bus bleed to <10 VDC within 60 seconds of power removal. Record:____ seconds.
| Overall test result:

Test Author: Bao Nguyen
| Test Case Name: | | Contactor Energize / De-energize Under PLC Control | | | Test ID #:
| Description: | | Verify the Mitsubishi SN35 contactor energizes and de-energizes correctly in response to PLC output commands. | | | Type: | | | ✓ white box □ black box □ _____________

Tester Information
| Name of Tester: | | | | | Date:
| HW/SW Version: | | 1.0 | | | Time:
| Setup: | | System powered, VFD at 0 Hz. PLC in RUN mode. Laptop with DirectSoft force table open. Multimeter in continuity mode. E-stop released, deadman switches released.
T E S T | INPUTS | | | EXPECTED OUTPUTS | | P A S S | F A I L | N/A | Comments
1 | PLC output to contactor coil = OFF (logic 0). Measure coil voltage and continuity across main contacts. | | | Coil voltage ~0 VDC. Main contacts OPEN: continuity = open circuit (inf ohm). No click.
2 | Force PLC output = ON (logic 1) via DirectSoft force table. Observe contactor. Measure coil voltage and contact continuity. | | | Audible click. Contacts CLOSED: <1 ohm. Coil voltage = control supply (24 VDC or 120 VAC)
3 | force PLC output = OFF. Observe contactor de-energize. Measure contact continuity. | | | Audible click. Contacts OPEN within 100 ms. Continuity = open circuit.
4 | Repeat energize/de-energize cycle 5 times. Note any chatter, delay, or failure to close/open. | | | Consistent response all 5 cycles. No chatter. No visible arcing. Record: ___/5 PASS.
| Overall test result:

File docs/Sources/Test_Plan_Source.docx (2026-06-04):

Universal Plastic Shredder V2.0 Electrical System Test Plan

Course: ECE 412 Senior Project Development, Portland State University

Sponsor: MME / Ichor Systems (Bridget Lannigan)

Team: Bao Nguyen, Fearghus Tyler, Yaqoub Rabiah, Fox Kang

Purpose

Verify the electrical control system of the Universal Plastic Shredder V2.0 using top-down and bottom-up testing methods.

Top-Down Test Summary

Requirement | Pass | Fail | Notes
M1 — Shreds to ~1"
M2 — VFD controllable
M4 — E-stop shutdown
M6 — Lid interlock
M7 — 70–90 RPM
M9 — HMI display
S1 — Status lights

BU-01: AC Power Input and Fuse Distribution

# | Input | Expected Output | Pass | Fail | N/A | Comments

1 | Main ON | Voltage at fuse input
2 | Main ON | Voltage at PSU input
3 | Main ON | Voltage at PLC input
4 | Remove fuse | PSU off, PLC unaffected

BU-05: Two-Hand Start Safety

# | Input | Expected Output | Pass | Fail | N/A | Comments

1 | Forward only | No start
2 | SW1 only | No start
3 | SW2 only | No start
4 | SW1+SW2+Fwd | Motor starts

Requirements Coverage Summary

Req ID | Requirement | Pass | Fail
M1 | Shred to ~1"
M4 | E-stop safe shutdown
M6 | Safety interlock
M7 | RPM range
M9 | HMI control
S1 | Indicator lights

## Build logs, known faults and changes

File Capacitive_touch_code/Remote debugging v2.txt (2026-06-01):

#include <Wire.h>
#include <WiFi.h>
#include <WebServer.h>

// --- Wi-Fi 配置 | Wi-Fi Settings ---
const char* ssid = "WIFI_NAME";     // 填写你的 WiFi SSID
const char* password = "WIFI_PASSWORD";  // 填写你的 WiFi 密码

WebServer server(80); // 创建 Web 服务器，端口 80

// --- 硬件引脚定义 | Hardware Pin Definitions ---
#define CAP1293_ADDR 0x28
#define RED_LED_PIN  12    
#define RELAY_PIN    5      
#define ENABLE_PIN   18     

// --- 全局变量 | Global Variables ---
String debugLog = "";      // 用于存储发送给网页的日志信息
bool isAlarmActive = false;
bool wasEnabled = false;

// --- 底层读写函数 ---
void writeRegister(byte reg, byte val) {
  Wire.beginTransmission(CAP1293_ADDR);
  Wire.write(reg);
  Wire.write(val);
  Wire.endTransmission();
}

byte readRegister(byte reg) {
  Wire.beginTransmission(CAP1293_ADDR);
  Wire.write(reg);
  Wire.endTransmission(false);
  Wire.requestFrom(CAP1293_ADDR, (uint8_t)1);
  return Wire.read();
}

// --- 处理网页请求 | Handle Web Requests ---
void handleRoot() {
  // 构建一个简单的 HTML 页面
  String html = "<html><head><meta charset='UTF-8'><meta http-equiv='refresh' content='1'></head>";
  html += "<body><h1>ESP32-S3 远程调试终端</h1>";
  html += "<h3>寄存器实时数据:</h3><pre>" + debugLog + "</pre>";
  html += "<p>页面每秒自动刷新一次</p></body></html>";
  server.send(200, "text/html", html);
}

void updateDebugLog() {
  byte reg00 = readRegister(0x00);
  byte reg03 = readRegister(0x03);
  byte reg1F = readRegister(0x1F);
  
  // 更新要显示在网页上的字符串
  debugLog = "Main (0x00): 0x" + String(reg00, HEX) + "\n";
  debugLog += "Touch (0x03): 0x" + String(reg03, HEX) + "\n";
  debugLog += "Sens (0x1F): 0x" + String(reg1F, HEX) + "\n";
  debugLog += "Time: " + String(millis() / 1000) + "s";
}

void setup() {
  Serial.begin(115200);
  pinMode(RED_LED_PIN, OUTPUT);
  pinMode(RELAY_PIN, OUTPUT);
  pinMode(ENABLE_PIN, INPUT_PULLUP);
  
  Wire.begin(3, 4);

  // 连接 Wi-Fi
  WiFi.begin(ssid, password);
  Serial.print("Connecting to WiFi...");
  while (WiFi.status() != WL_CONNECTED) {
    delay(500);
    Serial.print(".");
  }
  Serial.println("\nWiFi Connected!");
  Serial.print("IP Address: ");
  Serial.println(WiFi.localIP()); // 记住这个 IP 地址

  // 设置网页路由
  server.on("/", handleRoot);
  server.begin();

  // 初始化 CAP1293
  writeRegister(0x24, 0x01);
  writeRegister(0x1F, 0x05); 
  writeRegister(0x00, 0x00);
}

void loop() {
  server.handleClient(); // 处理网页访问
  
  static unsigned long lastUpdate = 0;
  if (millis() - lastUpdate > 500) {
    updateDebugLog(); // 每 0.5 秒更新一次内存中的寄存器值
    lastUpdate = millis();
  }

  // --- 原有的安防逻辑 ---
  bool isEnabled = (digitalRead(ENABLE_PIN) == HIGH);
  if (isEnabled) {
    byte status = readRegister(0x03);
    bool touchDetected = (status & 0x01);
    if (touchDetected && !isAlarmActive) {
      isAlarmActive = true;
      digitalWrite(RED_LED_PIN, HIGH);
      digitalWrite(RELAY_PIN, HIGH);
    }
    if (isAlarmActive || touchDetected) {
      byte mainCtrl = readRegister(0x00);
      writeRegister(0x00, mainCtrl & ~0x01);
    }
  } else {
    // 复位逻辑...
    isAlarmActive = false;
    digitalWrite(RED_LED_PIN, LOW);
    digitalWrite(RELAY_PIN, LOW);
  }
  
  delay(10); 
}

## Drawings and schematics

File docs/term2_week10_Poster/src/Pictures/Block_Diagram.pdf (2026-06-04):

# Rando

## fearghus tyler

## June 2026

1

## 1 Introduction

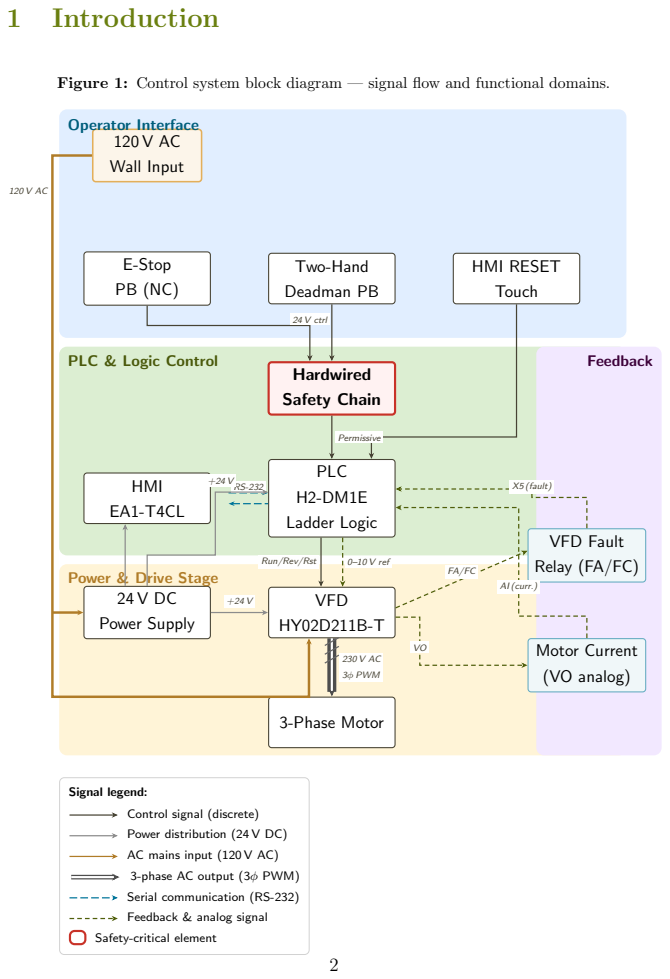
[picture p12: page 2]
Wall Input; E-Stop; Two-Hand; Deadman PB; HMI RESET; Touch; Hardwired; Safety Chain; PLC; Ladder Logic; HMI; VFD; Power Supply; 3-Phase Motor; Motor Current; (VO analog); Operator Interface; Feedback; 24 V ctrl; Permissive; Run/Rev/Rst; 0–10 V ref; 3ϕ PWM; X5 (fault); AI (curr.); Signal legend:

Figure 1: Control system block diagram — signal flow and functional domains.

PLC & Logic Control

VFD Fault
Relay (FA/FC)

Power & Drive Stage

Control signal (discrete)
Power distribution (24 V DC)
AC mains input (120 V AC)
3-phase AC output (3ϕ PWM)
Serial communication (RS-232)

Feedback & analog signal
Safety-critical element

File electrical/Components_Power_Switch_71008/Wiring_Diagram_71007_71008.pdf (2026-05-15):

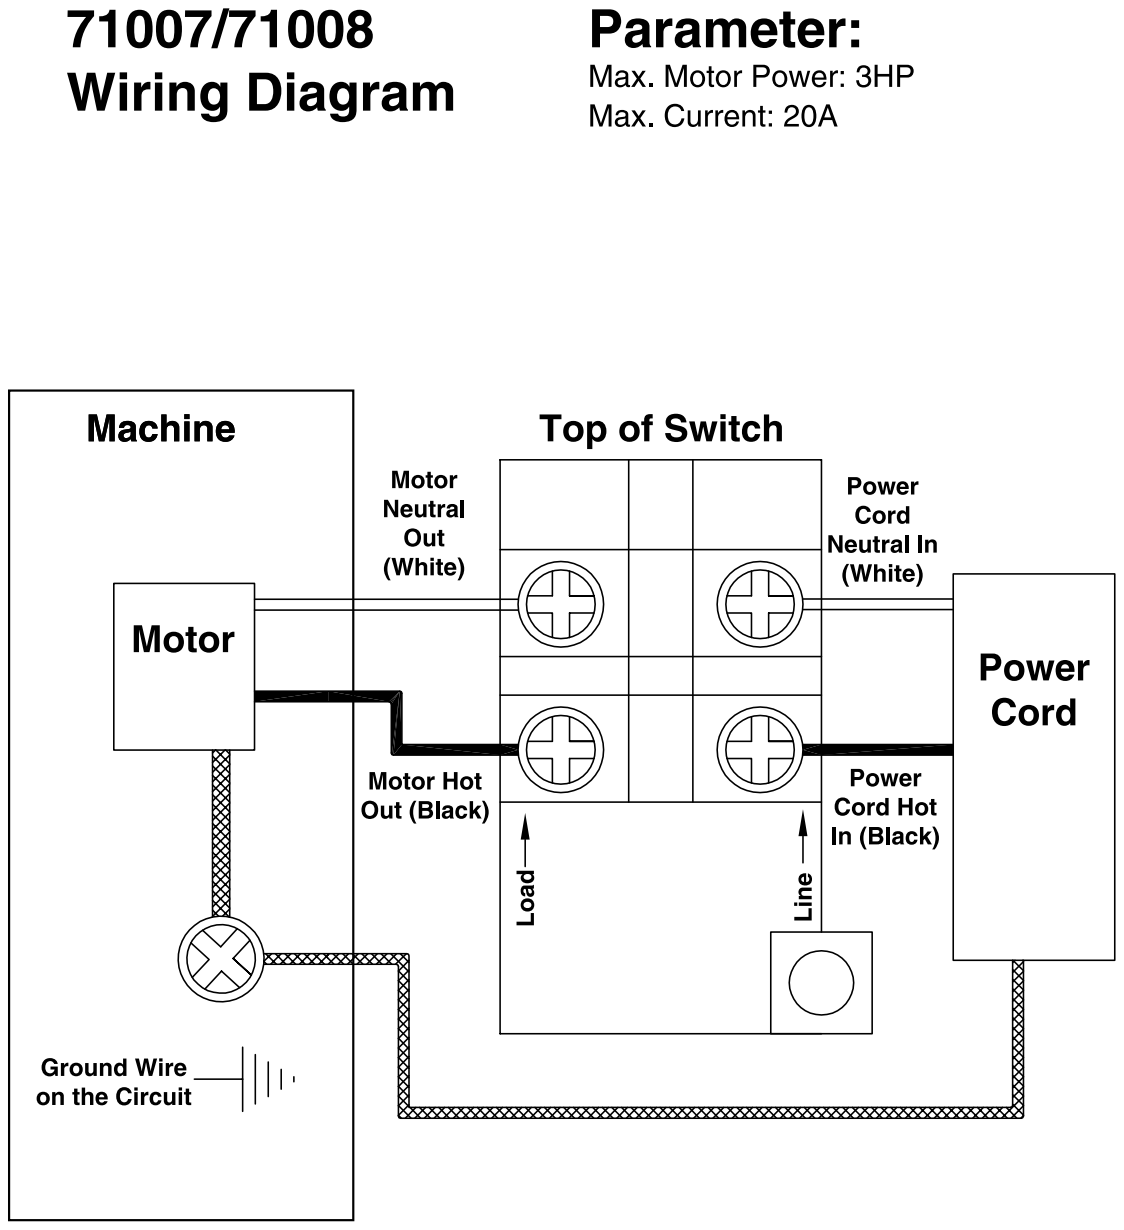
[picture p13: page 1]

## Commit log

2026-05-11 Add overcurrent (jam) signal wiring documentation
    Documents FA/FB/FC relay terminal roles, 500mA fuse sizing rationale,
    D2-08ND3 X4 input wiring, and required VFD parameter settings (PD052,
    PD123, PD124, PD125) for the over-torque jam detection signal.
2026-05-11 Add wire colors, gauge, and correct input address (X5)
    Adds NFPA 79 wire color coding section (blue for +24V DC, blue/white
    stripe for 0V return), 18 AWG gauge spec, ferrule terminations, and
    updates the jam signal input from X4 to X5.
2026-05-11 Add bench test procedure for jam signal validation
    Documents hand-load test method: lower PD124 to 70 and PD125 to 2.0
    so the shaft can be loaded by hand to trigger the over-torque alarm.
    Includes step-by-step procedure, safety notes, and restoration table.
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2026-05-11 Switch jam signal to fail-safe NC wiring (FB+FC)
    Updates the wiring from active-high NO (FA+FC) to fail-safe NC (FB+FC):
    - +24V wire moves from FA to FB; FC wire to PLC X5 stays
    - Polarity inverts: X5 HIGH = healthy, X5 LOW = jam OR signal failure
    - Adds rationale for fail-safe choice per NFPA 79 conventions
    - Documents all failure modes that now drive system to safe state
    - Adds PLC startup mask requirement (~5 s) to prevent boot-time false trips
    - Updates bench test procedure (X5 should be ON at idle, drops on trigger)
2026-05-11 Add brake resistor wiring documentation
    Documents the P+Pr terminal wiring for the dynamic braking resistor:
    - Why a brake resistor is required for the auto-clear FOR/REV cycling
    (regenerative energy from deceleration would otherwise trip the VFD
    on overvoltage)
    - Sizing guidance: 75 ohm / 500 W recommended for the 3 HP shredder
    - Wire gauge (14 AWG minimum), length (<1 m), and routing constraints
    - Physical mounting requirements (heat, airflow, clearance)
    - Safety notes (DC bus voltage, surface temperature, discharge time)
2026-05-11 Add guaranteed-trip verification test
    Adds a first-pass test section that uses very aggressive parameters
    (PD124=1, PD125=20, PD123=2) to guarantee the over-torque detection
    will trip regardless of motor load. Used to verify the full signal
    chain (VFD detection -> relay -> wiring -> PLC input -> ladder)
    end-to-end before fine-tuning the threshold for production. Includes
    failure-mode troubleshooting table for common test outcomes.
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2026-05-16 Add panel-wide wire color standard (NFPA 79 §13.2)
    Documents the wire color convention used throughout the shredder
    electrical panel: Black for AC power, Red for AC control, Blue for
    DC control / +24V, Blue/White stripe for DC return, Yellow for
    foreign voltage, Green/Green-Yellow for ground. Notes that wire
    labels are the primary identifier for DC signals since all blue,
    and lists specific examples from this build (jam signal, FOR/REV/RST,
    motor leads, brake resistor).
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2026-05-29 Update jam-signal doc to reflect as-built configuration
    Reflects the actual wiring and parameter settings used in the final
    build after today's commissioning and testing:
    - Wiring: FC + FA (NO pair, active-high), not FB + FC (NC fail-safe).
    PLC X5 reads HIGH when VFD trips, LOW when healthy.
    - PD052 = 02 (Fault Indication), not 12 (Over-torque Detect).
    Function 12 does not actuate the relay on this firmware revision
    when PD123 = 2 (continue running). Workaround: use fault indication
    with PD123 = 3 (stop on detect) so over-torque triggers a dT fault
    which fires the fault relay.
    - PD123 = 3 (stop on detect), not 0 (detect after set freq, continue
    running). VFD self-trips on over-t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
2026-05-29 Update Final Report rough draft to match as-built configuration
    Reflects the final wiring and parameter choices from today's
    commissioning:
    - Signal Flow section: VFD relay now wired FC+FA (NO, active-high),
    X5 = HIGH on fault. PLC outputs Y7=FOR, Y6=REV, Y5=RST documented
    with sinking (NPN) input mode.
    - Jam Detection Signal Chain section: full update to NO active-high
    topology, fail-safe failure mode now handled at safety-circuit
    layer rather than at jam-signal layer.
    - State Machine: X5 rising edge (not falling) triggers JAM_DETECTED.
    - Jam Counter Reset Logic: increments on rising edge of X5.
    - Startup Mask: rationale updated for NO wiring (defensive rather
    than required).
    - Fa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
2026-05-29 Add D2-08ND3 input mapping (X4=E-stop aux, X5=jam) + VFD control outputs (Y5-Y7)
    Documents what is currently known about the PLC I/O assignments.
    X4 reads the motor contactor's auxiliary contact, which reflects
    the hardwired E-stop chain state (NC contact opens when E-stop
    trips the contactor). X5 reads the VFD fault relay (NO active-high).
    Other inputs (X0-X3, X6, X7) marked TBD pending verification against
    the AutoCAD schematic.
    Also documents the D2-08TR relay output module driving the VFD's
    digital control inputs in sinking mode: Y7=FOR, Y6=REV, Y5=RST.
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2026-05-29 Document operator pushbutton BOM from URS Electronics invoice #828759
    Adds electrical/Operator_Controls.md with the verified Autonics
    pushbutton part numbers and Panduit wire duct sourced for the
    operator panel:
    - Forward (X0): S2PR-P3G + SA-LDG + SA-CA (green)
    - Reverse (X1): S2PR-P3Y + SA-LDY + SA-CA (yellow)
    - Deadman 1 (X2): S2PR-P3B + SA-LDB + SA-CA (blue, qty 2 ordered)
    - Deadman 2 (X3, likely): S2PR-P3B + SA-LDB + SA-CA (blue)
    - Reset (X6, tentative): S2PR-P3R + SA-LDR + SA-CA (red)
    - Wire duct: Panduit G1X1LG6 + C1LG6, 6 ft
    - Ferrules: Z+F V30AE000055, 12 AWG gray, 500 pack
    Corrected LED block naming throughout: SA-LDX (not SLA-LDX as
    previously documented). Verified against t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
2026-05-29 Correct X4 source: E22B1 E-stop button (not contactor aux)
    X4 is wired directly to the E-stop button line, not to an
    auxiliary contact on the Mitsubishi SD-N35 contactor as
    previously documented. The E22B1 NC contact is in series with
    the contactor coil A1; X4 taps the +24V at that node to monitor
    the safety chain state. Topology is inherently fail-safe (NC):
    any wire break or upstream failure reads LOW = E-stop active.
    E-stop part: Cutler-Hammer / Eaton E22B1, 22mm NC mushroom.
    Contactor coil A2 returns directly to PSU -V.
2026-05-29 Correct X5 jam-signal wiring: +24V on FA, FC to PLC X5
    Previously documented as +24V on FC and FA to PLC X5. The actual
    build has these swapped: +24V (through 500 mA fuse) lands on the
    FA terminal, and FC is the wire that goes back to PLC X5.
    Behavior is identical (it is a dry SPDT contact, either terminal
    can carry the +24V), but the documentation should match the actual
    wiring for accurate troubleshooting later.
    Updates:
    - vfd/Overcurrent_Signal_Wiring.md: relay terminal table, fuse
    description, wiring table, behavior summary, and troubleshooting
    hints all updated to FA=+24V, FC=X5
    - ai/io_map.md: X5 source description updated to match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
2026-05-29 Mark X6 reserved for Reset button, X7 spare
    X6 and X7 are currently unwired. X6 is reserved for the red
    illuminated reset pushbutton (Autonics S2PR-P3R from the URS
    invoice). When wired up, the PLC ladder will detect the rising
    edge of X6 (operator presses Reset) and pulse Y5 to drive the
    VFD RST terminal, clearing any latched VFD fault.
    This is the operator-facing reset that complements the automated
    Y5 pulse used inside the unjam routine.
    X7 is left as a spare input for future expansion.
2026-05-30 Add VFD master config file listing all programmed PD parameters
    Single doc capturing the as-built VFD configuration including the
    newly-documented PD054=1 (motor current monitor on VO terminal,
    0-10V scaled, read by F2-08AD-1 CH1+).
    Groups parameters by purpose:
    - Motor parameters (PD141-PD144) per nameplate
    - Over-torque detection (PD052, PD123, PD124, PD125)
    - Analog output (PD054, PD055) for current monitoring
    - Safety configuration (PD153, PD155) - auto-restart disabled
    - Other operational parameters with several TBD entries to verify
    Cross-links to motor nameplate, jam wiring, terminal reference,
    brake resistor, io_map, and the full PD codes manual.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
2026-05-30 Merge 6 new module sheets into Point List + update rack and PSU
    New sheets added:
    - Input Module (D2-08ND3) - X0-X7 + common
    - Analog Input (F2-08AD-1) - +24V, 0V, CH1+ (VFD VO current monitor), CH2-CH8 spare
    - RTD Input (F2-04RTD) - +24V, 0V, CH1-CH4 all spare
    - Relay Output (D2-08TR) - Y0-Y3 button LEDs, Y4 error light, Y5/Y6/Y7 VFD RST/FOR/REV, common
    - Analog Output (F2-08DA-2) - +24V, 0V, +V1 (VFD VI speed command), +V2-+V8 spare
    - VFD (Huanyang HY02D211B-T) - all 30 control + power terminals with as-built wiring
    Updated existing sheets:
    - Rack (D2-09B-1): Slot 3 corrected to F2-08AD-1, Slot 5 to D2-08TR, Slot 6 to F2-08DA-2
    - Mean Well NDR-480-24: rebuilt with full +V and -V distribut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
2026-05-31 Sync ai/ docs to updated Point List (6 new module sheets)
    Bring io_map.md and components.md in line with the as-built Point List:
    - Rack: Slot 3 F2-08AD-1, Slot 5 D2-08TR (relay), Slot 6 F2-08DA-2
    - D2-08TR outputs: Y0-Y4 indicator LEDs, Y5 RST, Y6 FOR, Y7 REV
    - SD-N35 contactor coil moved to hardwired E-stop chain (no longer Y0)
    - Added F2-08AD-1 (VFD VO current monitor) and F2-08DA-2 (VFD VI speed) sections
    - Added VFD terminal table incl. neutral-switched NFPA 79 deviation, banana
    sockets, brake resistor
    - Pushbutton fuse corrected to 1A; noted legacy D2-08TA / F2-02DAS-2 sheets
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2026-05-31 Correct HMI to EA1-T4CL and move HMI power to Mean Well NDR-480-24
    - HMI model corrected EA9-T6CL-R -> EA1-T4CL (4in C-More Micro-Graphic) in
    Point List (sheet tab renamed, title/CPU-row updated), io_map.md,
    components.md, Final report draft, and Test_Plan_v1.0.md
    - HMI power source changed Rhino PSB12-030-P -> shared Mean Well NDR-480-24;
    added +V/-V HMI distribution rows to the Mean Well sheet
    - Workbook edited via raw XML to preserve embedded images/drawings
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2026-05-31 Make final report standalone; clarify VFD jam relay uses only FA/FC
    - Jam detection: state only FA and FC are used (FB normally-closed contact
    unconnected); align FA=+24V / FC=X5 wiring to as-built point list; fix the
    failure-mode text that wrongly referenced FB-FC
    - Remove all external repository/file references and the Google Docs note so
    the report stands alone; embed content directly:
    - Appendix A: BOM table (flags PE145TC vs GE motor discrepancy)
    - Appendix B: full as-built I/O point list (rack, X/Y, analog, VFD terminals)
    - Appendix D: VFD parameter table (PD002/052/054/123/124/125/141-144)
    - Appendix E: Test Plan v1.0 case summary (top-down + BU-01..BU-10)
    - Recompiled P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
2026-05-31 Add professional PSU cover page; widen standards matrix, make it page-breakable
    - New title/cover page: PSU green branding, Maseeh College / ECE dept, capstone
    line, large project title, framed operator-panel image, team/sponsor/advisor
    block, and footer band (Portland, OR / date)
    - Standards Summary Matrix: convert to xltabular (breaks across pages with
    repeated header + 'continued' footer); shrink the Scope column and widen the
    'How it is applied here' column so it is no longer cramped
    - Recompiled PDF
2026-05-31 Reconcile motor (test = GE 5KE182BC205B, production TBD) and fix jam-signal rationale
    - Motor: frame GE 5KE182BC205B as the bench/test motor whose nameplate drives
    the VFD parameters (PD141-144); mark the final production motor TBD (3-5 HP)
    in System Architecture, NEC 430.6, BOM table/note, and Appendix D
    - Discussion: correct the jam-signal tradeoff to the as-built NO active-high
    wiring (was incorrectly stated as NC fail-safe), noting the broken-wire
    residual risk is covered by the hardwired E-stop loop and contactor
    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
2026-05-31 Restyle final report to match PSU MCECS report template
    Adopt the style of the team's switchgear (EE 347L) report:
    - PSU official colors; green section headings, blue subsection headings
    - HRule + MCECS-logo title page (replaces the previous custom cover); add
    docs/images/psuMCECSloghoriz.png
    - fancyhdr running header (project title / course) and footer (project line /
    page number) in PSU gray; 12pt, 1.2 line spacing
    - Move the operator-panel image into a captioned in-body figure
    - Add an Authors / Acknowledgements / Disclaimer closing section
2026-05-31 Tables for VFD params + all standards; fix table overflow and cover name wrapping
    - VFD programming as a table (param / what it does / value / why) in 5.2;
    Appendix D references it. Same table format applied to every standards
    subsection (NEC, NFPA 79, NEMA, ISO/IEC, OSHA) with vertical lines and a
    green header row; standards summary matrix gridded to match
    - Fix Appendix B tables running off the page (missing paragraph break before
    full-width tabularx); fix same overflow on the top/end note rules
    - Fill main disconnect rating (PowerTec 71008, 20A/3HP, 2-pole) and correct
    ferrule claims to straight wire (per as-built)
    - Cover: keep author names and advisor names from wrapping mid-n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
2026-05-31 Add ISO 13849-1 preliminary safety assessment; correct safety scope to as-built
    Verified the as-built control architecture from the ladder logic and point list:
    - Add 'Performance Level (ISO 13849-1) - Preliminary Assessment' with a table:
    hardwired E-stop ~ Cat 1, two-hand/deadman (standard-PLC software) ~ Cat B
    (not ISO 13851 Type III), over-torque = equipment protection. Overall Cat B-1
    / PL b-c; documents what is needed to reach Cat 3 / PL d
    - Remove lid interlock as an EE function (ME handles access mechanically; it was
    a may-have): updated exec summary, architecture, signal flow, safety circuit,
    hardwired-functions, standards tables, safety validation, ethics, Appendix E
    - Do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
2026-05-31 Add script to populate the Projects v2 board with the dated task backlog
    scripts/populate_project_board.py: creates draft cards on the user Projects
    board (BaoPSU/projects/1) via the GraphQL API, with Owner + Status + Start date
    (Jan->May 31, 2026) per task. Auto-creates the Start date and Owner fields if
    missing; idempotent (skips existing titles). Stdlib only; run with your own
    token (GITHUB_TOKEN or gh auth).
2026-05-31 docs: add weekly progress reports (Winter + Spring terms)
    Compiled team weekly progress reports for the full year (2025-12-17 through
    2026-06-06). Blank sections and missing hours were drafted/estimated and tagged
    '(draft — verify)' for the team to confirm before submission.
2026-05-31 docs: flesh out weekly-report drafts (detailed guesses, doc-focused final weeks, blocked sections)
    - Expanded drafted activity/plan entries into detailed best guesses.
    - Reframed Weeks 8-10 around documentation (final report, user manual,
    schematics) rather than building/testing a prototype.
    - Filled in blocked sections with plausible blockers (chiefly 'no shredder
    prototype to test on' in the back half).
    - Corrected advisor attribution (Ichor EE/controls team, not Andrew).
2026-05-31 docs: add technical specifics, readability index, and finalize weekly reports
    - Added key-hardware reference + scannable report index; emoji section markers.
    - Wove in real specifics: VFD params (PD002/052/054), terminals (VI/VO/FOR/REV/RST/FA/FC),
    PLC slots/points (X4/X5/X7, Y0-Y7, F2-08AD-1/F2-08DA-2/D2-08TR), conductor ratings,
    BOM add/changes, and AutoCAD block workflow.
    - Built out the ESP32 CTSI storyline (breadboard->soldered/enclosed, 24V->3V converter,
    optocoupler to X7, PC-vs-standalone power bug, fried/replaced ESP32).
    - Documented limitations: telemetry not fully implemented, HMI V/I/Hz/RPM partly
    non-operational, analog current monitor needs calibration (ran out of time)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
2026-06-01 Fix image references in Final Report - add missing wiring diagrams
    Five images are now correctly resolved in the report:
    - images/psuMCECSloghoriz.png (PSU MCECS logo, title page)
    - images/image.png (operator control panel layout)
    - images/Power.png (Power distribution wiring diagram) [newly added]
    - images/Motor.png (VFD and Motor wiring diagram) [newly added]
    - images/PLC.png (PLC and HMI wiring diagram) [newly added]
    Updated includegraphics paths in Final_Report_Rough_Draft.tex to use
    explicit 'images/' prefix so the figures resolve cleanly during
    pdflatex compilation. PDF now renders at 54 pages with all five
    figures embedded.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
2026-06-01 Consolidate BOMs into one and reorganize tex source under docs/src/
    BOM changes:
    - New BOM/BOM_Combined_As_Built.xlsx with three sheets:
    - Combined BOM (41 parts in 7 categories, as-built only)
    - Excluded - Not Used (21 items with reason)
    - VFD Decision Matrix (kept for traceability)
    - New BOM/BOM_Combined_As_Built.pdf (rendered for review)
    - Removed obsolete BOMs (BOM_02_20_26, BOM_1_29, BOM_1_30_beta,
    Motor Spec preliminary BOM 1_15_26, Motor Spec, VFD_120V_3HP_Decision_Matrix)
    Excluded items (per team confirmation):
    - Circuit Breaker NBE7 - never purchased; replaced by Phoenix TMC 8 3C 15A
    - Power Switch 71008 - kept (it is the main panel power switch)
    - HMI EA9-T6CL-R - not used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
    [BOM_02_20_26.xlsx, BOM_1_29.xlsx, BOM_1_30_beta.xlsx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]
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2026-06-01 BOM: rebuild matching original column layout, landscape PDF export
    - Restored the original BOM_1_29 column format: PART NUMBER /
    PART NAME / DESCRIPTION / QUANTITY / UNITS / LINK / UNIT COST /
    AMOUNT. Header block has PRODUCT NAME, APPROVED BY, DATE,
    PART COUNT, TOTAL COST, and EE team names.
    - Every row includes the actual manufacturer part number where
    known, plus quantity, units, unit cost, and computed amount.
    - PART COUNT and TOTAL COST in header use SUM formulas across the
    data range so they stay live.
    - All sheets configured for landscape Letter export, fit-to-width,
    with column header row repeated on each page. PDF no longer
    wraps awkwardly across portrait page breaks.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
    [BOM_Combined_As_Built.xlsx]
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2026-06-01 BOM: fix AMOUNT, PART COUNT, and TOTAL COST formulas
    After earlier row deletions, the SUM ranges in the header and
    totals row included the totals row itself (E8:E48 covering row 48
    which IS the totals row), causing recursive/erroneous totals.
    Also the last data row's AMOUNT formula was pointing at the totals
    row instead of its own row.
    Rebuilt all formulas:
    - Every data row's AMOUNT (col I) now correctly = E<row>*H<row>
    - TOTAL row sums only the actual data range (8 to last data row)
    - Header PART COUNT and TOTAL COST use the same correct range
    [BOM_Combined_As_Built.xlsx]
2026-06-01 BOM: brake resistor now LS Electric APCS-300R30-AD from AutomationDirect ($29)
    Original ATO-branded APCS-300R30-AD was ordered but never arrived
    after shipping. Replaced with the LS Electric APCS-300R30-AD (same
    part number / specifications) purchased from AutomationDirect for
    $29. Updated manufacturer, unit cost, link, and description.
    [BOM_Combined_As_Built.xlsx]
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2026-06-01 Final Report: integrate ladder logic rungs + HMI tag database
    Expanded the PLC Ladder Logic and HMI Programming sections with
    the full content from the supplemental report_additions PDF:
    PLC Ladder Logic (Section 6.1 area):
    - Complete variable / coil reference table (X/Y inputs, internal
    coils C0-C99, timers T0-T4, counters CT0, retentive registers
    V100/V2000/V3000, system bits)
    - Rung-by-rung narrative for all 31 rungs from the Do-more export
    - Jam Recovery Sequence timeline table (t=0 through lockout)
    - Original state machine summary and reset logic kept
    HMI Programming (Section 6.5):
    - Complete 27-tag HMI tag database (tag name, data type, PLC
    address, what it represents)
    - Per-sc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
2026-06-01 Remove outdated Final_draft.pdf from docs/final_report
    This earlier rendered PDF (894 KB, generated before the PLC ladder
    logic, HMI tag database, and rung-export image content was added)
    was a stale duplicate of the rough draft. The current report is
    docs/final_report/Final_Report_Rough_Draft.pdf (76 pages, 1.8 MB),
    which includes all the supplemental sections from the report
    additions PDF. Keeping a single up-to-date PDF avoids confusion
    between two divergent versions of the same report.
2026-06-01 Final Report: integrate rung images inline + restore Final_draft.pdf
    Restructured Section 6.1 (PLC Ladder Logic) Rung-by-Rung Description
    to interleave the actual ladder rung images directly with the text
    descriptions:
    Page 1 of 7: rungs 1-5 (power-up init and deadman permissive)
    Page 2 of 7: rungs 6-10 (RUN_REQUEST gating and run outputs)
    Page 3 of 7: rungs 11-16 (indicator LEDs and direction latches)
    Page 4 of 7: rungs 17-21 (E-stop response and jam detection chain)
    Page 5 of 7: rungs 22-26 (accumulating lockout timer and jam counter)
    Page 6 of 7: rungs 27-29 (fault reset, capacitive touch, screen change)
    Page 7 of 7: rungs 30-31 (screen reset timeout, end-of-program NOP)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
2026-06-01 Final Report: fix VFD parameter table column widths + resolve Table ?? ref
    - VFD parameter table (Table 1, Section 5.2): column widths were
    lopsided so 'Motor rated voltage' wrapped one word per line in the
    'What it does' column while 'Param' had idle slack. Converted to
    proportional X columns weighted .55 / 1.25 / .65 / 1.55 so the
    description columns get the space they need. Added the PSU green
    header bar with white text to match the other big tables in the
    report (variable map, HMI tag database, NEC table, ISO PL table).
    - Resolved 'Table ??' in Section 7.3 (Performance Level / ISO 13849-1).
    Label tab:pl existed but the prior compile sequence dropped the aux
    before the cr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
2026-06-01 Remove scripts/ folder (populate_project_board.py)
    One-shot helper that's already served its purpose populating the GitHub
    project board. No longer needed in the repo; remove the folder so the
    root layout reflects only deliverable / source content.
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2026-06-02 BOM: add Bao's Dignity (irrecoverable); README budget fix
    BOM_Combined_As_Built.xlsx now has one extra line item between the
    real parts and the totals row:
    DGN-001 Bao's Dignity Lost on the procurement loop after
    lowballing roughly every vendor between
    Portland and Beaverton. Quoted 'open-box'
    / 'educational discount' / 'the next one
    is on us' until even PowerTec stopped
    replying. Non-returnable. Replacement
    TBD; budget is hopefully zero.
    Qty 1 EA Unit cost $0 Amount $0
    It doesn't move the totals (uni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
    [BOM_Combined_As_Built.xlsx]
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2026-06-02 Reorganize top-level: VFD case + fold motor/ into VFD/
    The top-level folder listing was inconsistent: BOM, CAD, HMI, PLC
    were UPPERCASE three-letter subsystem codes, but 'vfd/' was lowercase.
    'motor/' held a single file (Motor_Nameplate.md) which made it dead
    weight in the directory listing.
    Changes:
    vfd/ -> VFD/
    motor/Motor_Nameplate.md -> VFD/Motor_Nameplate.md
    motor/ -> removed
    VFD/ now owns the motor nameplate, which is conceptually correct -- the
    motor's only relevance to this build is that its nameplate (5KE182BC205B
    test motor: 230 V, 7.6 A, 4 poles, 1750 RPM) drives the VFD parameters
    PD141--PD144. Keeping the two next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
    [VFD_Decision_Matrix.xlsx]
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
